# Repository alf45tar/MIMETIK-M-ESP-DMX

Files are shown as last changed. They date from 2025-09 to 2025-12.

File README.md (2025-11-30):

# DMX Smoke Machine Controller

DMX512 controller add-on for the **SDJ / Sagitter / Proel** [**MIMETIK-M**](https://www.sdjlighting.com/en/prodotto/sg-mimetikm-smoke-machine-mimetik-900w/)  smoke machine.
Provides pulse-based DMX smoke control with ready-state detection and a neat 3D-printed enclosure.

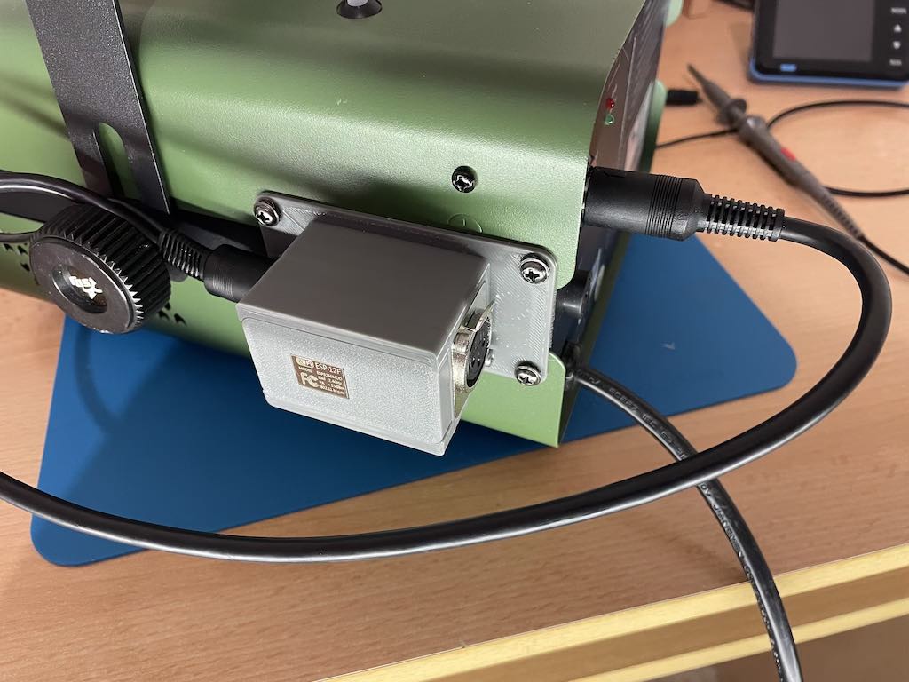
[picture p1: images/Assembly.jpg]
Assembly


## 💡 Compatibility
- ✅ Tested with **SDJ Mimetik-M**
- ⚠️ May also work with machines sharing the **same timer/remote port pinout**
- ❌ Not universal — always check wiring before use

## ✨ Features
- DMX512 input via RS485 transceiver
- READY/WARM-UP detection (machine won’t fire until warmed up)
- Pulse control: DMX value maps to **pulse duration** and **pulse period**
- Feedback PWM LED (DMX level, pin D6)
- Smoke pulse LED (mirrors smoke firing, pin D1)
- READY LED (pin D5)
- Compact 3D-printed enclosure
- Configuration [utility](https://github.com/alf45tar/ESP-DMX-Configuration) for macOS, Windows and Linux.

## ✨ New Feature: Wireless Art-Net & sACN Control
The MIMETIK-M-ESP-DMX can now receive DMX data **over Wi-Fi** using the **Art-Net** and **sACN (E1.31)** lighting network protocols.

This enables full wireless integration with professional lighting software compatible with Art-Net/sACN.

The ESP8266 receives Art-Net or sACN data and converts it internally into the same pulse-based smoke control logic used in wired DMX mode — maintaining full backward compatibility.

## ⚙️ Configuration with ESP-DMX-Configuration App
All network and DMX parameters (Wi-Fi credentials, protocol selection, universe, etc.) can be configured using the **[ESP-DMX-Configuration](https://github.com/alf45tar/ESP-DMX-Configuration)** application.

This app communicates directly with the device over **Wi-Fi**. No source code modification or re-compilation is required — all configuration can be done through the external app with the exception of DMX channel.

## 🛠 Bill of Materials
| Item | Quantity | Notes |
|---|---|---|
| Wemos D1 Mini or clone | 1 | Reference/tested board |
| D1 Mini ProtoBoard | 1 | ProtoBoard for Wemos D1 Mini |
| NA-Housing | 1 | 85 mm NA-Housing |
| Female XLR 3 pins | 1 | Panel mount female XLR 3 pins |
| DIN 5 pins socket | 1 | Panel mount DIN 5 pins 240° socket|
| MAX3485 | 1 | RS485 transceiver |
| PN2222 transistor | 1 | Smoke trigger driver |
| LEDs + resistors | optional | Status & feedback indicators |

## 📌 Timer Port Pinout
Pinout

| Label | Direction | Description |
|---|---|---|
| GND | Common | Ground reference |
| +5V | Output | **Low-current reference only** — cannot power Wemos D1 Mini |
| SMOKE | Input | Active LOW → pulling to GND triggers smoke |
| READY | Output | HIGH (3.5V) when warmed up, LOW during warm-up |
| NC | – | Not connected |

⚠️ **Important:** The +5V pin from the timer/remote port is **not able to supply enough current to run an Wemos D1 Mini**.

## 🔌 Wemos D1 Mini Pin Connections
| Wemos D1 Mini Pin | Function | Notes |
|---|---|---|
| `D1` | `SMOKE_PULSE_PIN` | LED mirrors smoke pulses |
| `D2` | `SMOKE_PIN` | Smoke trigger |
| `D3` | `DIRECTION_PIN` | DMX port direction |
| `D5` | `READY_LED_PIN` | LED mirrors READY |
| `D6` | `FEEDBACK_PIN` | PWM output showing DMX level |
| `D7` | `READY_PIN` | Input from machine READY |

# Schematic

## DMX connector wiring
```
Wemos D1 Mini                                                  DMX connector

    3V3  ----------------------------------------------+
                                                       |
                                  +---------------+    |
     RX  -------------------------| R         VCC |----+
                                  |               |
                             +----| RE/         B |----------  Data - (XLR pin 2)
                             |    |    MAX3485    |
     D3  --------------------+----| DE          A |----------  Data + (XLR pin 3)
                                  |               |
     D4  -------------------------| D         GND |---+------  Ground (XLR pin 1)
                                  +---------------+   |
                                                      |
    GND  ---------------------------------------------+
```

## DIN 5 pins cable wiring
```
                      Power Supply
                          +5V
                           +
Wemos D1 Mini              |                  MIMETIK-M Timer Port
                           |
     5V  ------------------+----------------  NC

     D7  -----------------------------------  READY

                           +----------------  SMOKE
                           |
                           |
                           |
                         | /  C
             470-680Ω    |/
     D2  -----\/\/\/\----|    PN22222         +5V (not connected)
                       B |\
                         | v  E
                           |
                           |
                           |
    GND  ------------------+----------------  GND
                           |
                           |
                           +
                          GND
                      Power Supply
```

## Led wiring (optional)
```
Wemos D1 Mini
               220Ω
     D5  -----\/\/\/\-----|>|-----+  Ready LED
                                  |
               220Ω               |
     D6  -----\/\/\/\-----|>|-----+  DMX feedback LED
                                  |
               220Ω               |
     D1  -----\/\/\/\-----|>|-----+  Smoke pulse LED
                                  |
                                  |
    GND  -------------------------+
```

## ⚙️ Software Behavior
- **DMX channel:** `503` (change in code if desired)
- **READY = LOW** → warm-up → smoke disabled
- **DMX mapping**
  - `0` = smoke OFF
  - `1` = short pulse (**0.1 s ON / 9.9 s OFF**)
  - `255` = continuous smoke (**1 s ON every 1 s cycle → always ON**)
  - Intermediate DMX values scale linearly between these extremes
- **Pulse cycle**
  - For each cycle:
    - Smoke ON for mapped duration
    - Smoke OFF until the mapped period completes
  - At DMX 255, duration = period → machine runs continuously
  - Responds instantly to DMX changes mid-cycle
- **LED indicators**
  - D5: LED follows READY state
  - D6: PWM LED shows DMX level
  - D1: LED mirrors smoke pulse (ON when machine is triggered)
- **Failsafe**
  - Smoke is forced OFF if:
      - Machine is warming up (READY LOW)
      - DMX signal is lost for >3s
      - DMX=0

## 📊 DMX Pulse Example
Pulse Example

## 🔧 PN2222 Transistor Notes

The **PN2222** is a common NPN bipolar junction transistor (BJT) used as a **switch** in the DMX smoke machine controller.

### Purpose

The Wemos D1 Mini’s digital output pin cannot directly drive the smoke machine’s timer input (which typically activates a coil inside the machine, like a relay) because the relay expects **higher current than the Arduino pin can safely supply**. The PN2222 acts as a **current amplifier** to safely trigger the smoke machine.

### How it Works

1. Weamos D1 Mini outputs a small current to the transistor **base** through a resistor (from 470Ω to 680Ω).
2. This turns the transistor **ON**, allowing current to flow from **collector to emitter**, which pulls the smoke trigger line LOW.
3. When the Arduino pin is LOW, the transistor switches OFF, and the smoke line returns to HIGH (inactive).

### Base Resistor Note

* The base resistor sets the current into the transistor’s base.
* It can be replaced with a resistor from **470Ω** to **680Ω** resistor depending on available components.

### Benefits

* Protects the Wemos D1 Mini from excessive current draw.
* Provides fast switching for precise smoke pulses.
* Compatible with standard 5V logic levels.
* Cheap, widely available, and reliable.

## Photos

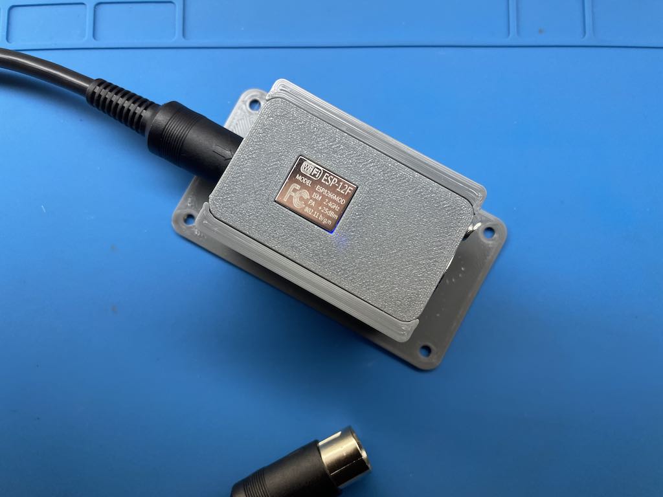
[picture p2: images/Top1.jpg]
Top1

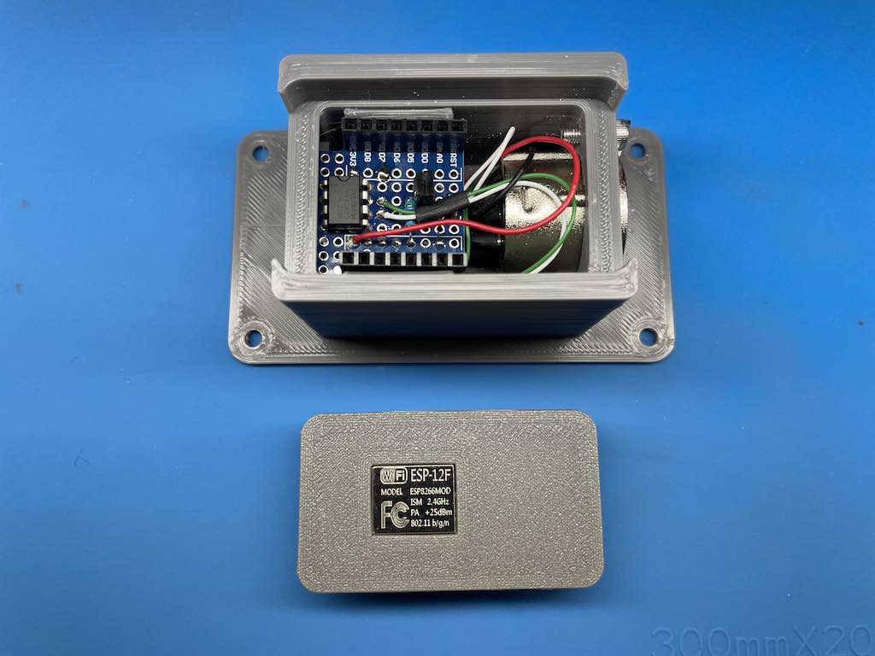
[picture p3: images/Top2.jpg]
Top2

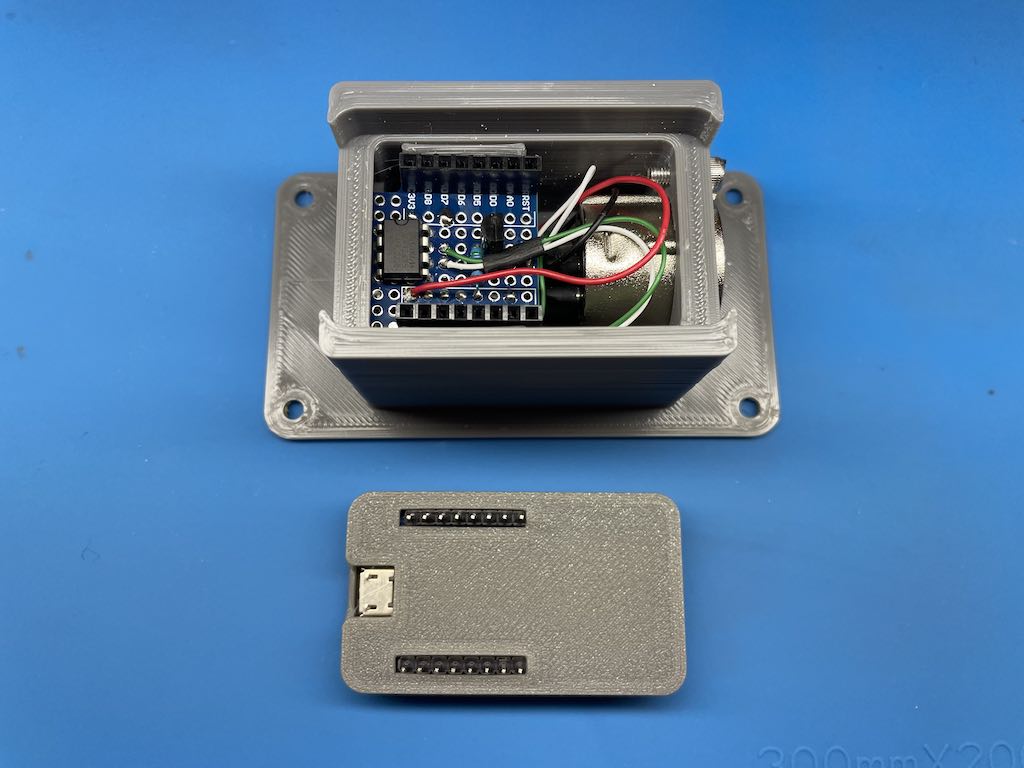
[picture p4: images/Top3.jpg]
Top3

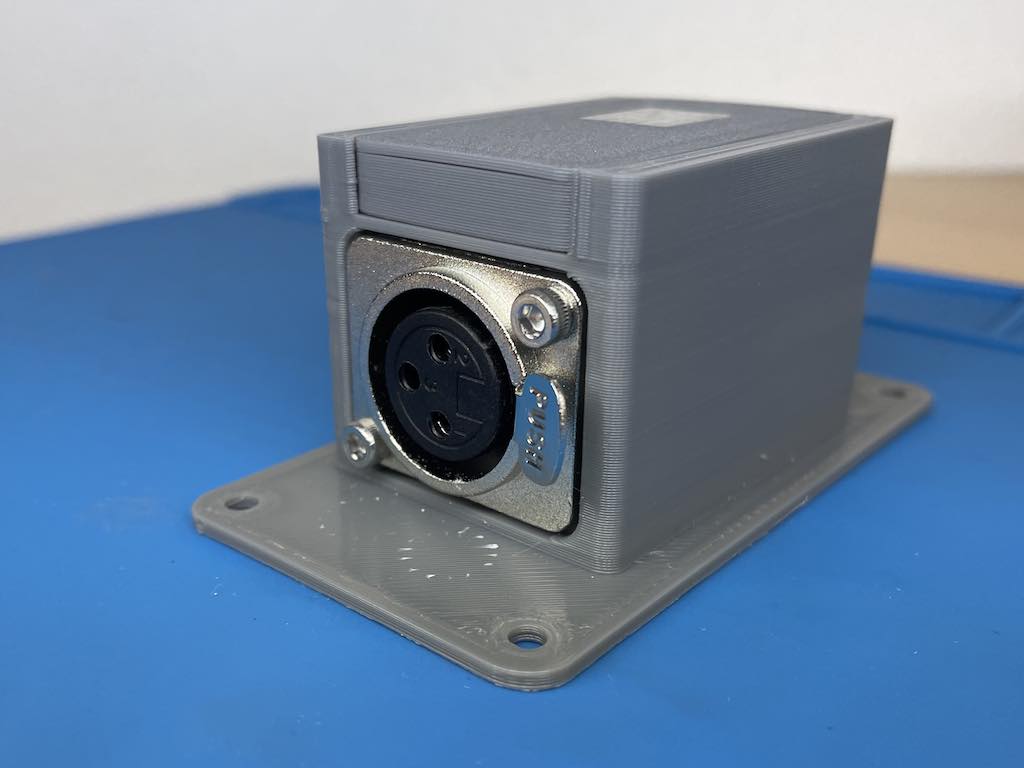
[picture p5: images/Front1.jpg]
Front

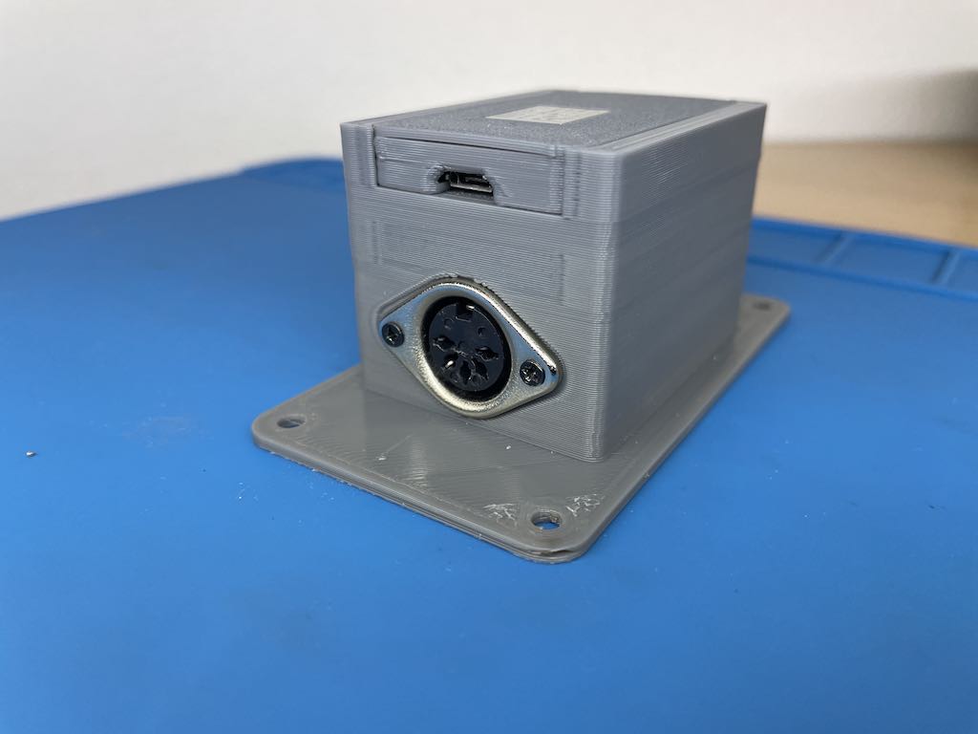
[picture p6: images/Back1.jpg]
Back


### Neutrik NA Housing

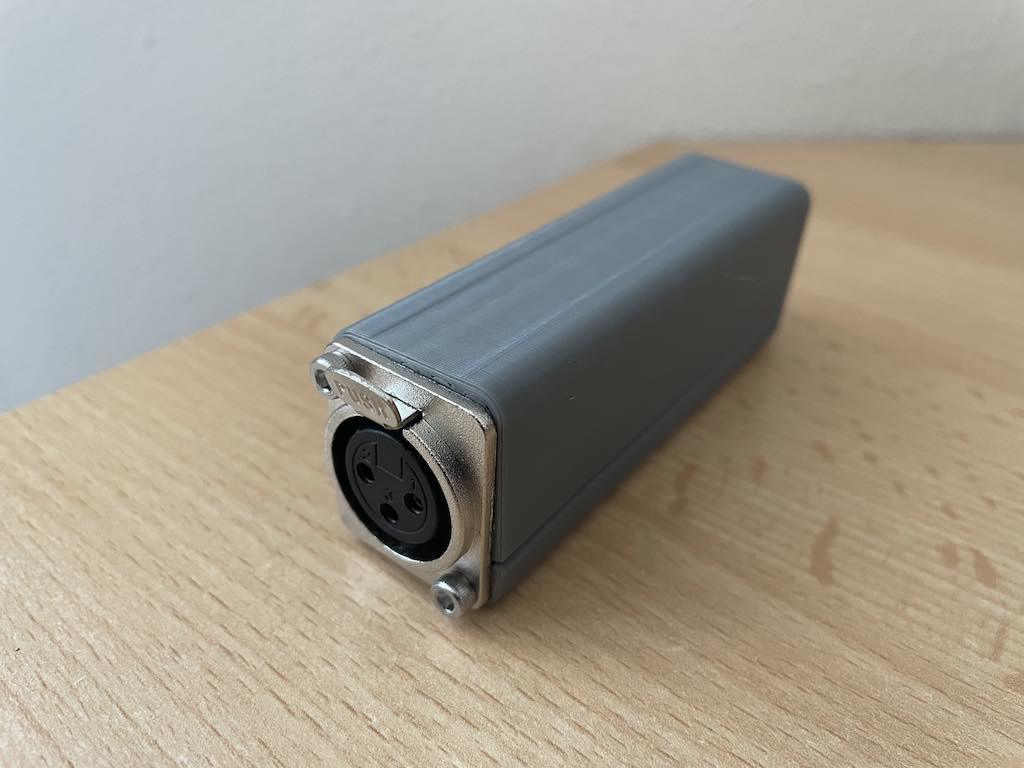
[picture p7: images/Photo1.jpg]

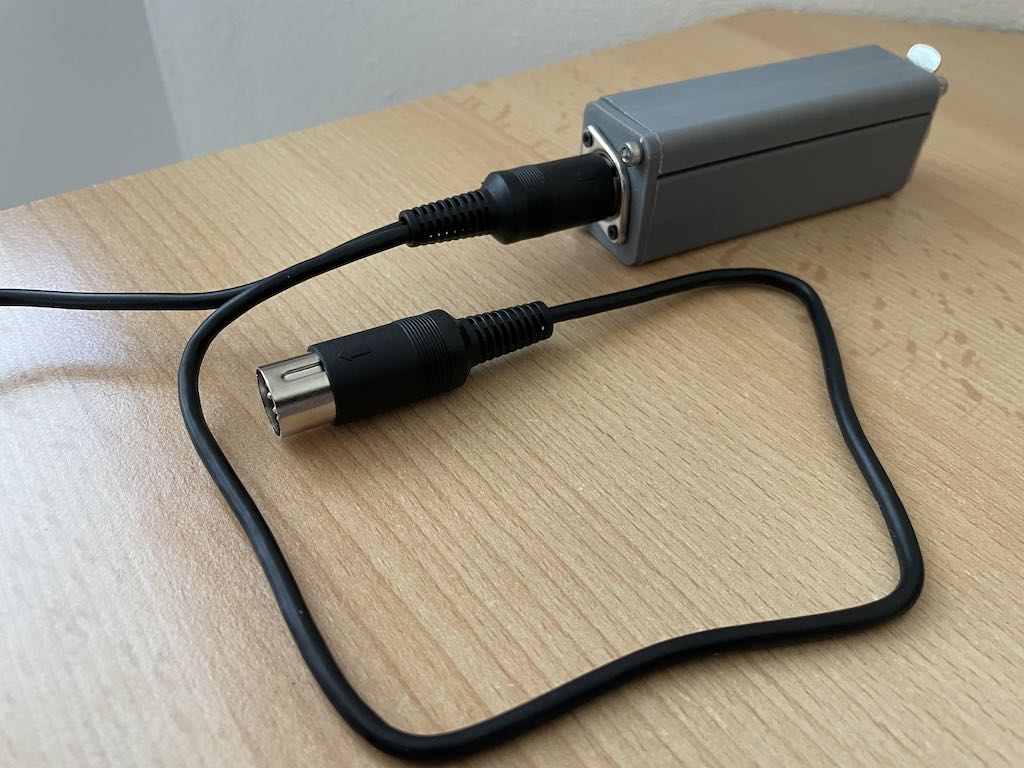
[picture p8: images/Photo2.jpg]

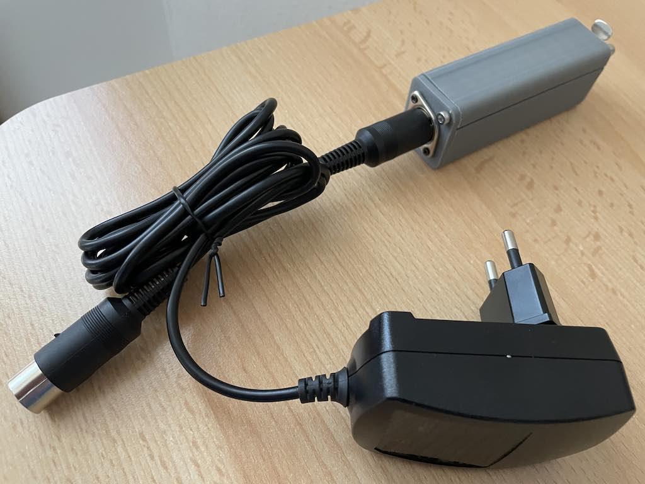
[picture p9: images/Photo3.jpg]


## ⚠️ Safety Notes
- Smoke machines run on **mains voltage** — isolate low-voltage electronics.
- Double-check wiring before powering on.
- Only use with machines confirmed to share the SDJ Mimetik-M pinout.
- ⚠️ The **+5 V timer port output cannot power the Wemos D1 Mini** (insufficient current).

## 📜 License
MIT License – free to use, adapt, and improve.

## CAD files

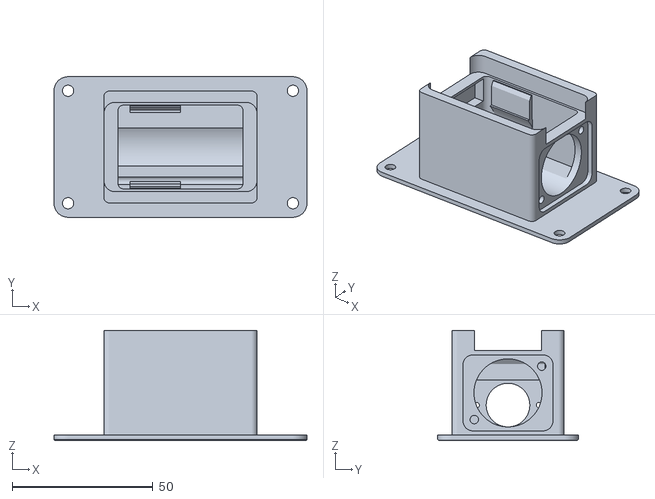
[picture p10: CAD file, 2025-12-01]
stl/Box.stl
90.0 x 50.0 x 39.2

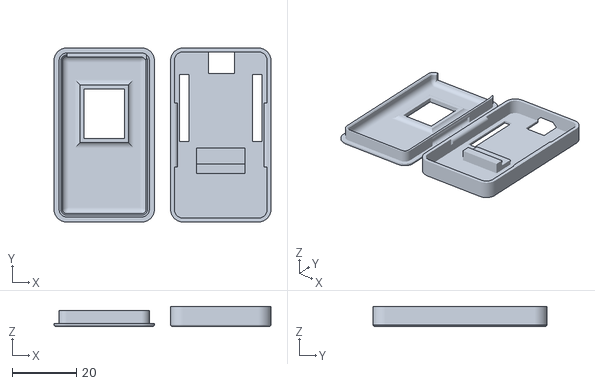
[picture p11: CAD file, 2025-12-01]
stl/Wemos Box.stl
67.8 x 54.4 x 6.25

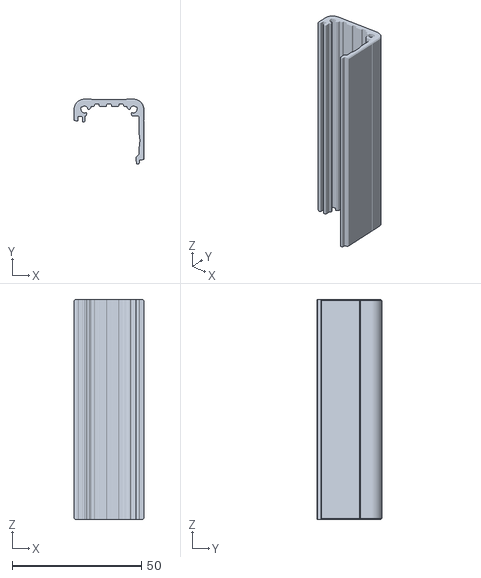
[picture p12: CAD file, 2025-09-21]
stl/NA-Housing-85mm.stl
27.0 x 25.0 x 85.0

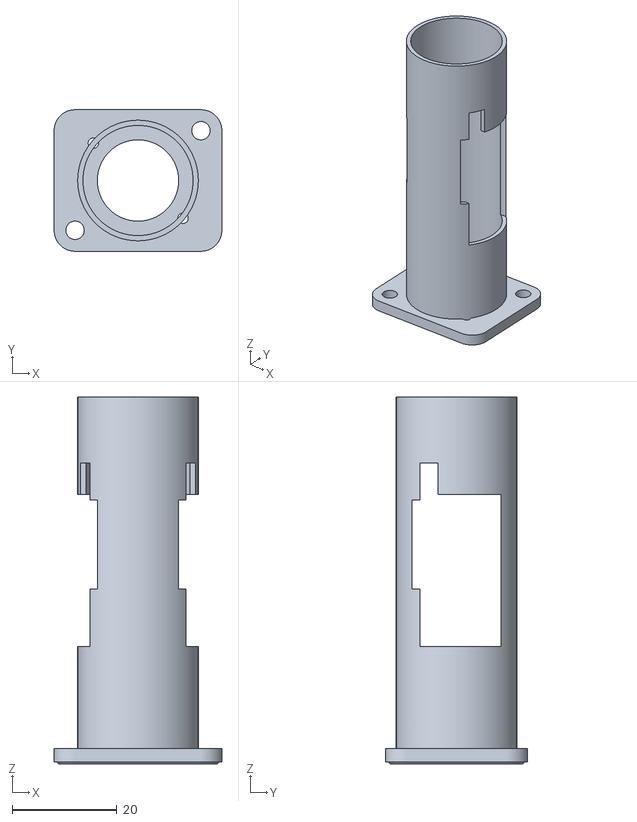
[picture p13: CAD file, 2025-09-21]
stl/NA-Housing-Backplate.stl
32.0 x 27.0 x 70.0

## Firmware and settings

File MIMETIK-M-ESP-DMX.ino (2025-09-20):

/**************************************************************************/
/*!
    @file     ESP-DMX.ino
    @author   Claude Heintz
    @license  BSD (see LXDMXWiFi.h)
    @copyright 2015-2021 by Claude Heintz All Rights Reserved

    Example using LXDMXWiFi_Library for output of Art-Net or E1.31 sACN from
    ESP 8266 WiFi connection to serial DMX.  Or, input from DMX to the network.
    Allows remote configuration of WiFi connection and protocol settings.
    
    Art-Net(TM) Designed by and Copyright Artistic Licence Holdings Ltd.
    sACN E 1.31 is a public standard published by the PLASA technical standards program
    
    Note:  For sending packets larger than 512 bytes, ESP8266 WiFi Library v2.1
           is necessary.
           
           This example requires the LXESP8266DMX library, v2.0 with RDM support
           https://github.com/claudeheintz/LXESP8266DMX

    @section  HISTORY

    v1.0 - First release
    v2.0 - Added remote configuration with DMXWiFiConfig packets
           Configure by holding pin 16 low on power up to force access point mode.
           Use python script esp_dmx_wifi_config.py to examine & change protocol and connection settings
    v3.0 - Renamed ESP-DMX, Combines output from network and input to network with remote configuration.
           Adds Java version of remote configuration utility.
    v3.1 - Updated for passing pointer to UDP object to LXDMXWiFi_Library functions.
           Moved remote config definitions and functions to separate files
    v4.0 - Listens for both Art-Net and sACN in output mode and merges HTP.
    		  Updated LXDMXWiFiConfig and improved remote configuration
    v4.1 - Supports Art-Net 3+ Port Addresses and additional poll reply information

    v5.0 - Adds RDM support (requires LXESP8266DMX library v2.0)
    v5.1 - Change to on demand RDM discovery
    		  RDM discovery runs for limited cycles at startup and after TOD request.
    		  
    v5.2 - Add USE_REMOTE_CONFIG option 

    v6.0 - Refactor to clarify functionality
           -move RDM functions to separate file
           -move Art-Net callbacks and other functions to below setup and loop in main .ino file

    v6.1 - Refactor to move setup of WiFi connection and config packet handling to LXDMXWiFiConfig
*/
/**************************************************************************/

#include "wifi_dmx_rdm.h"

#include <ESP8266WiFi.h>
#include <WiFiUdp.h>
#include "LXDMXWiFi.h"
#include <LXWiFiArtNet.h>
#include <LXWiFiSACN.h>
#include <EEPROM.h>
#include "LXDMXWiFiConfig.h"
#include "SmokeController.h"

#define BUILTIN_LED       D4     // GPIO2 Pin shared with UART1 TX
#define STARTUP_MODE_PIN  TX     // GPIO1 Pin for force default setup when LOW (using INPUT_PULLUP to force HIGH when disconnected)
                                 // When connection to Station fail or timeout happens, it starts with default configuration (AP mode). There is no need to have a startup button.
#define DIRECTION_PIN     D3     // GPIO0 Pin for output direction enable on MAX485 chip

// MIMETIK-M smoke machine configuration

#define SMOKE_DMX_CHANNEL 503

#define READY_PIN         D7     // GPIO13 Input from machine READY
#define READY_LED_PIN     D5     // GPIO14 LED mirrors READY
#define SMOKE_PIN         D2     // GPIO4  Smoke trigger
#define SMOKE_PULSE_PIN   D1     // GPIO5  LED mirrors smoke pulses
#define FEEDBACK_PIN      D6     // GPIO12 PWM output showing DMX level to drive a LED intensity

SmokeController smoke(READY_PIN, READY_LED_PIN, SMOKE_PIN, SMOKE_PULSE_PIN, FEEDBACK_PIN);    // Use -1 to disable a feature

/*         
 *  To allow use of the configuration utility, uncomment the following statement
 *  to define USE_REMOTE_CONFIG.
 *
 *  When using remote configuration:
 *        The remote configuration utility can be used to edit the settings
 *        without re-loading the sketch.  Settings from persistent memory are
 *        used unless the startup pin is read LOW.  Holding the startup pin low
 *        temporarily uses the settings in the LXDMXWiFiConfig.initConfig() method.
 *        This insures there is a default way of connecting to the sketch
 *        in order to use the remote utility, even if it is configured to use
 *        a WiFi network that is unavailable.
 *
 *	Without remote configuration (USE_REMOTE_CONFIG remains undefined):
 *        Settings are read from the LXDMXWiFiConfig.initConfig() method.
 *        So, it is necessary to edit that function in order to change
 *        the settings.
 *
 *  Important for using remote configuration:
 *        It is necessary to initialize the boards EEPROM flash with the
 *        following steps.
 *
 *       ------------------------------------------------
 *        1) In ESP-DMX.ino line 99 should read:
 *           #define USE_REMOTE_CONFIG 0
 *
 *        2) In LXDMXWiFiConfig.cpp uncomment line 35:
 *           #define RESET_PERSISTENT_CONFIG_ON_DEFAULT 1
 *
 *        3) Flash the ESP8266 and reboot.
 *
 *        4) In LXDMXWiFiConfig.cpp comment out line 35:
 *           //#define RESET_PERSISTENT_CONFIG_ON_DEFAULT 1
 *
 *        5) Flash the ESP8266 and reboot.
*       --------------------------------------------------
 */
#define USE_REMOTE_CONFIG 0

// dmx protocol interfaces for parsing packets (created in setup)
LXWiFiArtNet* artNetInterface;
LXWiFiSACN*   sACNInterface;

// EthernetUDP instances to let us send and receive UDP packets
WiFiUDP aUDP;
WiFiUDP sUDP;

// direction output from network/input to network
uint8_t dmx_direction = 0;

// Output mode: received packet contained dmx
int art_packet_result = 0;
int acn_packet_result = 0;

// Input mode:  received slots when inputting dmx to network
int got_dmx = 0;

// used to toggle indicator LED on and off
uint8_t led_state = 0;

/************************************************************************/
/************************************************************************

  Setup creates the WiFi connection.
  
  It also creates the network protocol object,
  either an instance of LXWiFiArtNet or LXWiFiSACN.
  
  if OUTPUT_FROM_NETWORK_MODE:
     Starts listening on the appropriate UDP port.
  
     And, it starts the ESP8266DMX sending serial DMX via the UART1 TX pin.
     (see the LXESP8266DMX library documentation for driver details)
     
   if INPUT_TO_NETWORK_MODE:
     Starts ESP8266DMX listening for DMX ( received as serial on UART0 RX pin. )

*************************************************************************/

void setup() {
  //Serial.begin(115200);
  Serial.setDebugOutput(1); //use uart0 for debugging  UART0
  pinMode(BUILTIN_LED, OUTPUT);
  pinMode(STARTUP_MODE_PIN, INPUT_PULLUP);
  pinMode(DIRECTION_PIN, OUTPUT);

#ifdef USE_REMOTE_CONFIG
  uint8_t bootStatus = DMXWiFiConfig.begin(digitalRead(STARTUP_MODE_PIN));	// uses settings from persistent memory unless pin is low. 
#else
  uint8_t bootStatus = DMXWiFiConfig.begin();								// must edit DMXWiFiConfig.initConfig() to change settings
#endif
  uint8_t dhcpStatus = 0;
  
  dmx_direction = DMXWiFiConfig.inputToNetworkMode();
  setRDMisEnabled(DMXWiFiConfig.rdmMode());


  if ( rdmIsEnabled() ) {
    if ( dmx_direction ) {
      ESP8266DMX.startRDM(DIRECTION_PIN, 0);  // start RDM in input task mode
    } else {
      ESP8266DMX.startRDM(DIRECTION_PIN);     // defaults to RDM output task mode
    }
  } else if ( dmx_direction ) {					      // DMX Driver startup based on direction flag
    Serial.println("starting DMX input");
    ESP8266DMX.setDirectionPin(DIRECTION_PIN);
    ESP8266DMX.setDataReceivedCallback(&gotDMXCallback);
    ESP8266DMX.startInput();
  } else {
    ESP8266DMX.setDirectionPin(DIRECTION_PIN);
    ESP8266DMX.startOutput();
  }

  // -------------------   WiFi  ------------------- 

  Serial.print("initializing wifi... ");
  
  uint8_t wifi_result = DMXWiFiConfig.setupWiFi(blinkLED);
  
  if ( wifi_result & LX_AP_MODE ) {
    Serial.print("created access point ");
    Serial.println(DMXWiFiConfig.SSID());
  } else {
    if ( ( wifi_result & STATIC_MODE ) == 0 ) {
      dhcpStatus = 1;
    }
    Serial.println("wifi started.");
  }
 
  
  //------------------- Initialize network<->DMX interfaces -------------------
    
  sACNInterface = new LXWiFiSACN();							
  sACNInterface->setUniverse(DMXWiFiConfig.sACNUniverse());

  artNetInterface = new LXWiFiArtNet(WiFi.localIP(), WiFi.subnetMask());
  artNetInterface->setUniverse(DMXWiFiConfig.artnetPortAddress());	//setUniverse for LXArtNet class sets complete Port-Address
  artNetInterface->setArtAddressReceivedCallback(&artAddressReceived);
  artNetInterface->setArtIpProgReceivedCallback(&artIpProgReceived);
  artNetInterface->setArtIndicatorReceivedCallback(&artIndicatorReceived);
  if ( rdmIsEnabled() ) {
    artNetInterface->setArtTodRequestCallback(&artTodRequestReceived);
    artNetInterface->setArtRDMCallback(&artRDMReceived);
  }
  artNetInterface->setArtCommandCallback(&artCmdReceived);
  char* nn = DMXWiFiConfig.nodeName();
  if ( nn[0] != 0 ) {
    strcpy(artNetInterface->longName(), nn);
  }
  artNetInterface->setStatus2Flag(ARTNET_STATUS2_SACN_CAPABLE, 1);
  artNetInterface->setStatus2Flag(ARTNET_STATUS2_DHCP_CAPABLE, 1);
  if ( dhcpStatus ) {
  	 artNetInterface->setStatus2Flag(ARTNET_STATUS2_DHCP_USED, 1);
  }
  if ( bootStatus ) {
    artNetInterface->setStatus1Flag(ARTNET_STATUS1_FACTORY_BOOT, 1);
  }
  if ( rdmIsEnabled() ) {
    artNetInterface->setStatus1Flag(ARTNET_STATUS1_RDM_CAPABLE, 1);
  }
  Serial.print("interfaces created, ");
  
  // start _UDP objects
	if ( DMXWiFiConfig.multicastMode() ) {
		if ( DMXWiFiConfig.APMode() ) {
			sUDP.beginMulticast(WiFi.softAPIP(), DMXWiFiConfig.multicastAddress(), sACNInterface->dmxPort());
		} else {
			sUDP.beginMulticast(WiFi.localIP(), DMXWiFiConfig.multicastAddress(), sACNInterface->dmxPort());
		}
	} else {
		sUDP.begin(sACNInterface->dmxPort());
	}
  
  aUDP.begin(artNetInterface->dmxPort());
  if ( dmx_direction == 0 ) {  
    artNetInterface->send_art_poll_reply(&aUDP);
  } else {
    artNetInterface->send_art_poll_reply(&aUDP, ARTPOLL_INPUT_MODE);
  }
  Serial.print("udp started listening,");

  smoke.begin();
  
  Serial.println(" setup complete.");
  blinkLED();
} //setup


/************************************************************************

  Main loop
  
  if OUTPUT_FROM_NETWORK_MODE:
    checks for and reads packets from WiFi UDP socket
    connection.  readDMXPacket() returns true when a DMX packet is received.
    
    If dmx is received on either interface, copy from both (HTP) to dmx output.
  
    If the packet is an CONFIG_PACKET_IDENT packet, the config struct is modified and stored in EEPROM
  
  if INPUT_TO_NETWORK_MODE:
    if serial dmx has been received, sends an sACN or Art-Net packet containing the dmx data.
    Note:  does not listen for incoming packets for remote configuration in this mode.

*************************************************************************/

void loop() {
	if ( dmx_direction ) {    //direction is input to network
  
		if ( DMXWiFiConfig.sACNMode() ) {
		  checkInput(sACNInterface, &sUDP, DMXWiFiConfig.multicastMode());
		} else {
		  checkInput(artNetInterface, &aUDP, 0);
      /*
		  art_packet_result = artNetInterface->readArtNetPacketInputMode(&aUDP);
		  #ifdef USE_REMOTE_CONFIG
		  if ( art_packet_result == RESULT_NONE ) {
			  DMXWiFiConfig.checkConfigReceived(artNetInterface, aUDP, blinkLED, CONFIG_PRINT_MESSAGES);
		  }
      #endif
      */
      art_packet_result = artNetInterface->readDMXPacket(&aUDP);
      #ifdef USE_REMOTE_CONFIG
      if ( art_packet_result == RESULT_NONE ) {
        DMXWiFiConfig.checkConfigReceived(artNetInterface, aUDP, blinkLED, CONFIG_PRINT_MESSAGES);
      }
      #endif
    
      acn_packet_result = sACNInterface->readDMXPacket(&sUDP);
      #ifdef USE_REMOTE_CONFIG
      if ( acn_packet_result == RESULT_NONE ) {
        DMXWiFiConfig.checkConfigReceived(sACNInterface, aUDP, blinkLED, CONFIG_PRINT_MESSAGES);
      }
      #endif
    
      if ( (art_packet_result == RESULT_DMX_RECEIVED) || (acn_packet_result == RESULT_DMX_RECEIVED) ) {
          copyDMXToSmokeController();
      }
		}
	} else {                  //direction is output from network
  
		art_packet_result = artNetInterface->readDMXPacket(&aUDP);
		#ifdef USE_REMOTE_CONFIG
		if ( art_packet_result == RESULT_NONE ) {
			DMXWiFiConfig.checkConfigReceived(artNetInterface, aUDP, blinkLED, CONFIG_PRINT_MESSAGES);
		}
		#endif
	
		acn_packet_result = sACNInterface->readDMXPacket(&sUDP);
		#ifdef USE_REMOTE_CONFIG
		if ( acn_packet_result == RESULT_NONE ) {
			DMXWiFiConfig.checkConfigReceived(sACNInterface, aUDP, blinkLED, CONFIG_PRINT_MESSAGES);
		}
		#endif
	
		if ( (art_packet_result == RESULT_DMX_RECEIVED) || (acn_packet_result == RESULT_DMX_RECEIVED) ) {
		  copyDMXToOutput();
		  blinkLED();
		  resetRDMIdleCount();
		} else {
		  updateRDM(artNetInterface,aUDP);
		}
		
	}                  //direction is output from network
	
  smoke.update();

}// loop()

/************************************************************************/
/************************************************************************
   utility function to toggle indicator LED on/off
*/
void blinkLED() {
  if ( led_state ) {
    digitalWrite(BUILTIN_LED, HIGH);
    led_state = 0;
  } else {
    digitalWrite(BUILTIN_LED, LOW);
    led_state = 1;
  }
}

/*
  DMX input callback function sets number of slots received by ESP8266DMX.
  Input is handled in the main loop by calling checkInput which copies the 
  received values to the network interface if got_dmx is non-zero.
*/

void gotDMXCallback(int slots) {
  got_dmx = slots;
}

/************************************************************************

  Checks to see if the dmx callback indicates received dmx
     If so, send it using the selected interface.
  
*************************************************************************/

void checkInput(LXDMXWiFi* interface, WiFiUDP* iUDP, uint8_t multicast) {
  if ( got_dmx ) {
    interface->setNumberOfSlots(got_dmx);     // set slots & copy to interface
    for(int i=1; i<=got_dmx; i++) {     
      if (i == SMOKE_DMX_CHANNEL) {
        smoke.setDMXValue(ESP8266DMX.getSlot(i));
      }
      interface->setSlot(i, ESP8266DMX.getSlot(i));
    }
    if ( multicast ) {
      interface->sendDMX(iUDP, DMXWiFiConfig.inputAddress(), WiFi.localIP());
    } else {
      interface->sendDMX(iUDP, DMXWiFiConfig.inputAddress(), INADDR_NONE);
    }
    got_dmx = 0;
    blinkLED();
  }   // <- got_dmx
}

/************************************************************************

  Copy to output merges slots for Art-Net and sACN on HTP basis
  
*************************************************************************/

void copyDMXToOutput(void) {
  uint8_t a, s;
  uint16_t a_slots = artNetInterface->numberOfSlots();
  uint16_t s_slots = sACNInterface->numberOfSlots();
  for (int i=1; i <=DMX_UNIVERSE_SIZE; i++) {
    if ( i <= a_slots ) {
      a = artNetInterface->getSlot(i);
    } else {
      a = 0;
    }
    if ( i <= s_slots ) {
      s = sACNInterface->getSlot(i);
    } else {
      s = 0;
    }
    if ( a > s ) {
        ESP8266DMX.setSlot(i , a);
        if (i == SMOKE_DMX_CHANNEL)
          smoke.setDMXValue(a);
      } else {
        ESP8266DMX.setSlot(i , s);
        if (i == SMOKE_DMX_CHANNEL)
          smoke.setDMXValue(s);
      }
   }
}

/************************************************************************

  Copy to output merges slots for Art-Net and sACN on HTP basis
  
*************************************************************************/

void copyDMXToSmokeController(void) {
  uint8_t a, s;
  uint16_t a_slots = artNetInterface->numberOfSlots();
  uint16_t s_slots = sACNInterface->numberOfSlots();
  for (int i=1; i <=DMX_UNIVERSE_SIZE; i++) {
    if ( i <= a_slots ) {
      a = artNetInterface->getSlot(i);
    } else {
      a = 0;
    }
    if ( i <= s_slots ) {
      s = sACNInterface->getSlot(i);
    } else {
      s = 0;
    }
    if ( a > s ) {
        if (i == SMOKE_DMX_CHANNEL)
          smoke.setDMXValue(a);
      } else {
        if (i == SMOKE_DMX_CHANNEL)
          smoke.setDMXValue(s);
      }
   }
}

/************************************************************************
 *          Art-Net Implementation Callback Functions
 ************************************************************************/


/* 
   artAddress callback allows storing of config information
   artAddress may or may not have set this information
   but relevant fields are copied to config struct and stored to EEPROM
*/
void artAddressReceived() {
  DMXWiFiConfig.setArtNetPortAddress( artNetInterface->universe() );
  DMXWiFiConfig.setNodeName( artNetInterface->longName() );
  DMXWiFiConfig.commitToPersistentStore();
}

void artTodRequestReceived(uint8_t* type) {
  if ( type[0] ) {
    rdmTOD().reset();
  }
  setRDMDiscoveryEnable(10);
  artNetInterface->send_art_tod(&aUDP, rdmTOD().rawBytes(), rdmTOD().count());
}

void artRDMReceived(uint8_t* pdata) {
  uint8_t plen = pdata[1] + 2;
  uint8_t j;

  //copy into ESP8266DMX outgoing packet
  uint8_t* pkt = ESP8266DMX.rdmData();
  for (j=0; j<plen; j++) {
    pkt[j+1] = pdata[j];
  }
  pkt[0] = 0xCC;

  // reply from RDM to network
  if ( ESP8266DMX.sendRDMControllerPacket() ) {
    artNetInterface->send_art_rdm(&aUDP, ESP8266DMX.receivedRDMData(), aUDP.remoteIP());
  }
}

void artCmdReceived(uint8_t* pdata) {
  if ( strcmp((const char*)pdata, "clearSACN") == 0 ) {
    sACNInterface->clearDMXOutput();
  }
}

/* 
   artIpProg callback allows storing of config information
   cmd field bit 7 indicates that settings should be programmed
*/
void artIpProgReceived(uint8_t cmd, IPAddress addr, IPAddress subnet) {
   if ( cmd & 0x80 ) {
      if ( cmd & 0x40 ) { //enable dhcp, other fields not written
        if ( DMXWiFiConfig.staticIPAddress() ) {
          DMXWiFiConfig.setStaticIPAddress(0);
        } else {
           return;  // already set to dhcp
        }
      } else {
         if ( ! DMXWiFiConfig.staticIPAddress() ) {
           DMXWiFiConfig.setStaticIPAddress(1); // static not dhcp
        }
        if ( cmd & 0x08 ) { //factory reset
           DMXWiFiConfig.initConfig();
        } else {
           if ( cmd & 0x04 ) {  //programIP
              DMXWiFiConfig.setStationIPAddress(addr);
           }
           if ( cmd & 0x02 ) {  //programSubnet
              DMXWiFiConfig.setStationSubnetMask(subnet);
           }
        }
      } // else ( ! dhcp )
      
      DMXWiFiConfig.commitToPersistentStore();
   }
}

/*
  Indicator was request by ArtAddress packet
*/
void artIndicatorReceived(bool normal, bool mute, bool locate) {
    if (normal) {
        Serial.println("Normal mode");
    } else if (mute) {
        Serial.println("Mute mode");
    } else if (locate) {
        Serial.println("Locate mode");
    }
}

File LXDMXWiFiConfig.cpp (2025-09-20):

/**************************************************************************/
/*!
    @file     LXDMXWiFiconfig.cpp
    @author   Claude Heintz
    @license  BSD (see LXDMXWiFi.h or http://lx.claudeheintzdesign.com/opensource.html)
    @copyright 2016 by Claude Heintz All Rights Reserved

    Edit initConfig for your own default settings.
*/
/**************************************************************************/

#include <Arduino.h>
#include <IPAddress.h>
#include <EEPROM.h>
#include "LXDMXWiFiConfig.h"


DMXwifiConfig DMXWiFiConfig;

/*******************************************************************************
 ***********************  DMXwifiConfig member functions  ********************/

DMXwifiConfig::DMXwifiConfig ( void ) {
	
}

DMXwifiConfig::~DMXwifiConfig ( void ) {
	if ( _temp_config ) {
		free(_wifi_config);
	}
}

// uncomment the following line to force an overwrite of the configuration back to
// the hard coded settings when the boot mode is default (mode==0)
//#define RESET_PERSISTENT_CONFIG_ON_DEFAULT 1

uint8_t DMXwifiConfig::begin ( uint8_t mode ) {
	if ( mode ) {
		_temp_config = 0;
		EEPROM.begin(DMXWiFiConfigSIZE);                      		// get pointer to data
  		_wifi_config = (DMXWiFiconfig*)EEPROM.getDataPtr();
  	
		// data already read, check initialization
		if (( strcmp(CONFIG_PACKET_IDENT, (const char *) _wifi_config) != 0 ) ||
			( _wifi_config->version > DMXWIFI_CONFIG_INVALID_VERSION )) {	          // if structure not previously stored or invalid version
		  initConfig();																  // initialize and store in EEPROM
		  commitToPersistentStore();
		  Serial.println("\nInitialized EEPROM");
		} else {																	  // otherwise use the config struct read from EEPROM
			  Serial.println("\nEEPROM Read OK");
			  return 0;
		}
		
	} else {					// default creates temporary config pointer
#ifdef RESET_PERSISTENT_CONFIG_ON_DEFAULT
        _temp_config = 0;
        EEPROM.begin(DMXWiFiConfigSIZE);
		_wifi_config = (DMXWiFiconfig*)EEPROM.getDataPtr();
		initConfig();
		commitToPersistentStore();
#else
		_temp_config = 1;	// readFromPersistentStore() will free this pointer and replace it with data from EEPROM
		_wifi_config = (DMXWiFiconfig*) malloc(sizeof(DMXWiFiconfig));
		initConfig();
#endif
		Serial.println("\nDefault configuration.");
	}
	
	return 1;
}

void DMXwifiConfig::initConfig(void) {
  //zero the complete config struct
  memset(_wifi_config, 0, DMXWiFiConfigSIZE);
  
  strncpy((char*)_wifi_config, CONFIG_PACKET_IDENT, 8); //add ident
  _wifi_config->version = DMXWIFI_CONFIG_VERSION;
  _wifi_config->wifi_mode = LX_AP_MODE;                            // LX_AP_MODE or LX_STATION_MODE
  _wifi_config->protocol_flags = MULTICAST_MODE | RDM_MODE;     // sACN multicast mode
  																	                            // optional: | INPUT_TO_NETWORK_MODE specify ARTNET_MODE or SACN_MODE
  																	                            // optional: | STATIC_MODE   to use static not dhcp address for station
                                                                // eg. _wifi_config->protocol_flags = MULTICAST_MODE | INPUT_TO_NETWORK_MODE | SACN_MODE;
  strncpy(_wifi_config->ssid, "ESP-DMX-WiFi", 63);
  strncpy(_wifi_config->pwd, "", 63);
  _wifi_config->ap_address    = IPAddress(10,110,115,10);       // ip address of access point
  _wifi_config->ap_gateway    = IPAddress(10,110,115,10);
  _wifi_config->ap_subnet     = IPAddress(255,255,255,0);       // match what is passed to dchp connection from computer
  _wifi_config->sta_address   = IPAddress(10,110,115,15);       // station's static address for STATIC_MODE
  _wifi_config->sta_gateway   = IPAddress(192,168,1,1);
  _wifi_config->sta_subnet    = IPAddress(255,0,0,0);
  _wifi_config->multi_address = IPAddress(239,255,0,1);         // sACN multicast address should match universe
  _wifi_config->sacn_universe      = 1;
  _wifi_config->sacn_universe_hi   = 0;
  _wifi_config->artnet_portaddr_lo = 0;
  _wifi_config->artnet_portaddr_hi = 0;
  _wifi_config->device_address  = 1;
  strcpy((char*)_wifi_config->node_name, "com.claudeheintzdesign.esp-dmx");
  _wifi_config->input_address = IPAddress(10,255,255,255);
}
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

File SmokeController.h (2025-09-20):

#pragma once
#include <Arduino.h>

class SmokeController {
public:
    enum State { IDLE, PULSING, WAITING, FULL_ON };

    using StateChangeCallback = void (*)(State);
    using SimpleCallback      = void (*)();

    SmokeController(int readyPin, int readyLedPin,
                    int smokePin, int pulseLedPin, int feedbackPin,
                    unsigned long dmxTimeout = 3000, bool enableFailsafe = true,
                    uint16_t minPulse = 100, uint16_t maxPulse = 900,
                    uint16_t maxPeriod = 10000, uint16_t minPeriod = 1000)
        : readyPin(readyPin), readyLedPin(readyLedPin),
          smokePin(smokePin), pulseLedPin(pulseLedPin), feedbackPin(feedbackPin),
          dmxTimeout(dmxTimeout), failsafeEnabled(enableFailsafe),
          minPulse(minPulse), maxPulse(maxPulse),
          maxPeriod(maxPeriod), minPeriod(minPeriod) {}

    void begin() {
        if (readyPin >= 0) pinMode(readyPin, INPUT_PULLUP);
        if (readyLedPin >= 0) pinMode(readyLedPin, OUTPUT);
        if (pulseLedPin >= 0) pinMode(pulseLedPin, OUTPUT);
        if (feedbackPin >= 0) pinMode(feedbackPin, OUTPUT);
        if (smokePin >= 0) pinMode(smokePin, OUTPUT);

        smokeOff();
        lastDMXMillis = millis();
        lastTransitionTime = millis();
    }

    // Caller provides the latest DMX value (0–255)
    void setDMXValue(byte value) {
        dmxValue = value;
        lastDMXMillis = millis();
    }

    // Register callbacks
    void onStateChange(StateChangeCallback cb) { stateCb = cb; }
    void onSmokeOn(SimpleCallback cb)          { smokeOnCb = cb; }
    void onSmokeOff(SimpleCallback cb)         { smokeOffCb = cb; }

    void update() {
        unsigned long now = millis();

        // READY state (always true if readyPin == -1)
        bool readyState = (readyPin >= 0) ? digitalRead(readyPin) : true;

        // READY indicator LED mirrors machine status (if enabled)
        if (readyLedPin >= 0) {
            digitalWrite(readyLedPin, !readyState);
        }

        // Warm-up handling
        if (readyState != prevReadyState) {
            prevReadyState = readyState;
            if (readyState) {
                nextPulseTime = now;  // can start immediately
            } else {
                smokeOff();
            }
        }

        if (!readyState) {
            smokeOff();
            return;
        }

        // --- DMX failsafe ---
        if (failsafeEnabled && (millis() - lastDMXMillis > dmxTimeout)) {
            if (feedbackPin >= 0) analogWrite(feedbackPin, 0);
            smokeOff();
            return;
        } else {
            if (feedbackPin >= 0) analogWrite(feedbackPin, 255-dmxValue);
        }

        // DMX = 0 → OFF
        if (dmxValue == 0) {
            smokeOff();
            return;
        }

        // DMX = 255 → FULL_ON
        if (dmxValue == 255) {
            if (state != FULL_ON) smokeFullOn();
            return;
        } else if (state == FULL_ON) {
            smokeOff(); // Exit FULL_ON
        }

        // --- Pulsing logic ---
        byte safeValue = constrain(dmxValue, 1, 254);
        uint16_t newPulseDuration = map(safeValue, 1, 254, minPulse, maxPulse);
        uint16_t newPeriod        = map(safeValue, 1, 254, maxPeriod, minPeriod);

        if (state == PULSING) {
            unsigned long elapsed = now - pulseStartTime;
            if (elapsed >= newPulseDuration) {
                smokeOff();
                nextPulseTime = now + (newPeriod - newPulseDuration);
                changeState(WAITING);
            } else {
                pulseDuration = newPulseDuration;
                period = newPeriod;
            }
        }
        else if (state == WAITING) {
            unsigned long remaining = (nextPulseTime > now) ? nextPulseTime - now : 0;
            if (remaining > newPeriod - newPulseDuration) {
                nextPulseTime = now + (newPeriod - newPulseDuration);
            }
            pulseDuration = newPulseDuration;
            period = newPeriod;

            if (now >= nextPulseTime) smokeOn();
        }
        else if (state == IDLE) {
            pulseDuration = newPulseDuration;
            period = newPeriod;
            if (now >= nextPulseTime) smokeOn();
        }
    }

    // --- Public queries ---
    State getState() const { return state; }
    byte getDMXValue() const { return dmxValue; }

    unsigned long timeSinceTransition() const {
        return millis() - lastTransitionTime;
    }

    unsigned long timeSinceSmokeOn() const {
        if (isSmokeActive()) return millis() - lastTransitionTime;
        return 0;
    }

    unsigned long timeSinceSmokeOff() const {
        if (!isSmokeActive()) return millis() - lastTransitionTime;
        return 0;
    }

    bool isSmokeActive() const {
        return (state == PULSING || state == FULL_ON);
    }

private:
    // --- Pins & config ---
    int readyPin, readyLedPin, smokePin, pulseLedPin, feedbackPin;
    unsigned long dmxTimeout;
    bool failsafeEnabled;

    // --- Timing ranges ---
    uint16_t minPulse, maxPulse;
    uint16_t maxPeriod, minPeriod;

    // --- Timing state ---
    uint16_t pulseDuration = 200;
    uint16_t period        = 5000;
    unsigned long pulseStartTime = 0;
    unsigned long nextPulseTime  = 0;
    unsigned long lastDMXMillis  = 0;
    unsigned long lastTransitionTime = 0;

    // --- State ---
    State state = IDLE;
    byte dmxValue = 0;
    bool prevReadyState = false;

    // --- Callbacks ---
    StateChangeCallback stateCb = nullptr;
    SimpleCallback smokeOnCb    = nullptr;
    SimpleCallback smokeOffCb   = nullptr;

    // --- Helpers ---
    void smokeOn() {
        if (smokePin >= 0) digitalWrite(smokePin, HIGH);
        if (pulseLedPin >= 0) digitalWrite(pulseLedPin, HIGH);
        pulseStartTime = millis();
        changeState(PULSING);
        if (smokeOnCb) smokeOnCb();
    }

    void smokeFullOn() {
        if (smokePin >= 0) digitalWrite(smokePin, HIGH);
        if (pulseLedPin >= 0) digitalWrite(pulseLedPin, HIGH);
        changeState(FULL_ON);
        if (smokeOnCb) smokeOnCb();
    }

    void smokeOff() {
        if (state != IDLE && state != WAITING) {
            if (smokeOffCb) smokeOffCb();
        }
        if (smokePin >= 0) digitalWrite(smokePin, LOW);
        if (pulseLedPin >= 0) digitalWrite(pulseLedPin, LOW);
        changeState(IDLE);
    }

    void changeState(State newState) {
        if (newState != state) {
            state = newState;
            lastTransitionTime = millis();
            if (stateCb) stateCb(state);
        }
    }
};

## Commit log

2025-09-20 Update README with cable connection details
2025-09-20 Revise wiring instructions in README.md
2025-09-20 Fix formatting in DMX connector wiring diagram
2025-09-20 Revise cable wiring and power options in README
2025-09-20 Fix formatting issues in README.md wiring diagram
2025-09-21 Update Bill of Materials in README
2025-10-08 Revise connections section for Wemos D1 Mini
    Updated Arduino connections section to specify Wemos D1 Mini pin connections and added important notes about power supply.
2025-10-22 Revise Bill of Materials in README.md
    Updated the Bill of Materials section with corrected item names and formatting.
2025-11-07 Document new Wireless Art-Net & sACN control feature
    Added details about the new wireless DMX control feature and configuration app.
